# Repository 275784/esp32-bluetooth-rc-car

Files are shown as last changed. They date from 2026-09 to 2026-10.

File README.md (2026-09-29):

# ESP32 Bluetooth RC Car

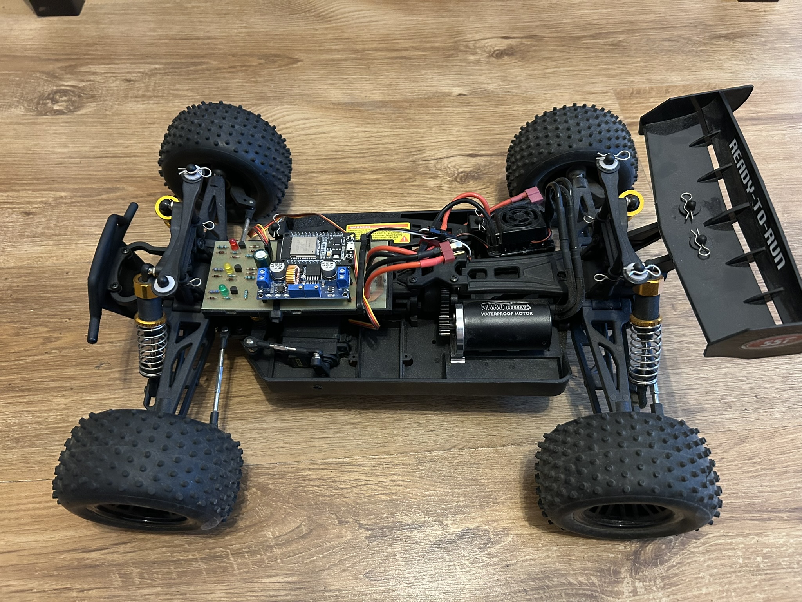
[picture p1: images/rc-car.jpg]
RC Car


Wireless RC vehicle controlled by an Xbox controller over Bluetooth.

The vehicle uses an ESP32-DevKitV1 as the main controller. The ESP32 receives commands from the Xbox controller, processes the input and generates PWM signals for the ESC and steering servo.

The system also includes a custom PCB, power distribution, battery status indication and software safety mechanisms.

## Features

- Xbox controller input over Bluetooth
- ESP32-based control system
- Brushless motor control through ESC
- Servo-based steering
- Progressive acceleration (Soft Start)
- Safe direction switching through neutral
- Run / Stop functionality
- Normal and Sport driving modes
- Battery voltage indication
- Custom PCB
- Fail-safe behavior after Bluetooth disconnection

## System Architecture

```text
Xbox Controller
      │
   Bluetooth
      │
      ▼
    ESP32
   │     │
   │     └──────► Steering Servo
   │
   └────────────► ESC ─────► Brushless Motor

LiPo Battery
      │
      ├──────────► Power Distribution
      ├──────────► Voltage Indicator
      │
      └──────────► XL4015 Step-Down
                         │
                         ├────► ESP32
                         └────► Servo
```

## How It Works

1. The Xbox controller connects to the ESP32 over Bluetooth.
2. The ESP32 reads the controller inputs and processes the commands.
3. Throttle and steering inputs are converted into PWM signals for the ESC and steering servo.
4. The battery voltage is indicated by a dedicated analog LED circuit.
5. If the Bluetooth connection is lost, the vehicle returns to a safe state.

## Hardware

- ESP32-DevKitV1
- Brushless motor
- Electronic Speed Controller (ESC)
- Steering servo
- LiPo battery
- XL4015 step-down converter
- Custom PCB
- Battery voltage indicator

## Software

- C++
- Arduino IDE
- ESP32
- Bluepad32
- ESP32Servo
- Bluetooth
- PWM

## Motor Control

The brushless motor is controlled through an Electronic Speed Controller (ESC) using a 50 Hz PWM signal.

The firmware uses:

- `1000 µs` — minimum
- `1500 µs` — neutral
- `2000 µs` — maximum

Two driving modes are available:

- **Normal**
- **Sport**

A Soft Start mechanism limits the rate at which the motor command increases.

## Steering Control

Steering is controlled using the horizontal axis of the Xbox controller.

A configurable dead zone prevents unwanted steering caused by small joystick movements.

The joystick input is mapped to the steering servo PWM range for proportional steering control.

## Safety Features

The firmware includes several mechanisms designed to prevent uncontrolled movement:

- motor output returns to neutral when the controller disconnects
- steering returns to the center position
- switching between forward and reverse requires passing through neutral
- Run / Stop functionality
- trigger dead zone
- steering dead zone
- controlled acceleration

## Hardware Design

The project includes a custom PCB integrating the ESP32, ESC interface, steering servo interface, power distribution and analog battery voltage indicator.

The PCB was designed in KiCad and the battery voltage indicator was analyzed in LTspice.

### PCB Design

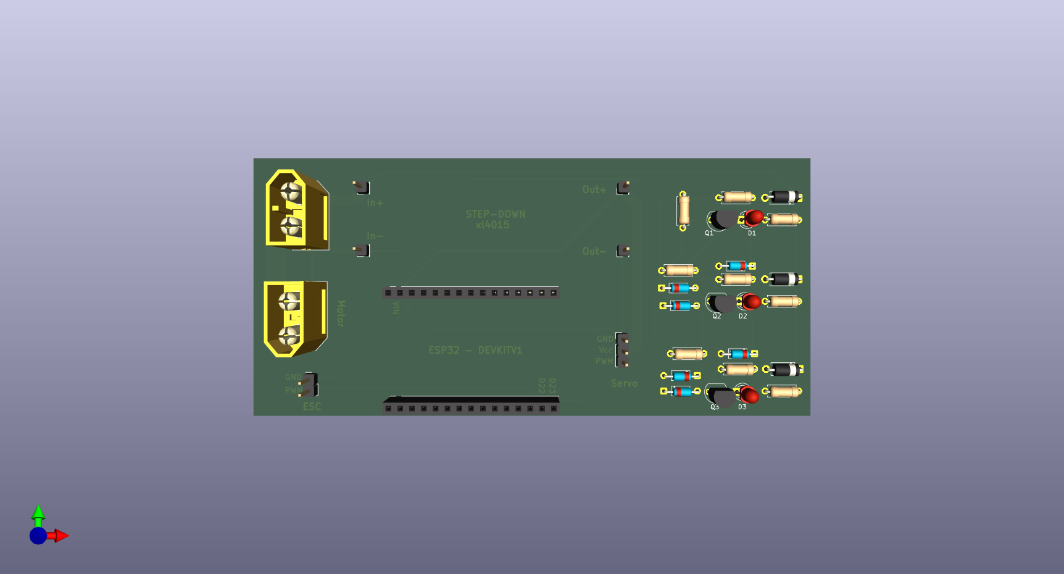
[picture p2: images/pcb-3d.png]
PCB 3D Design


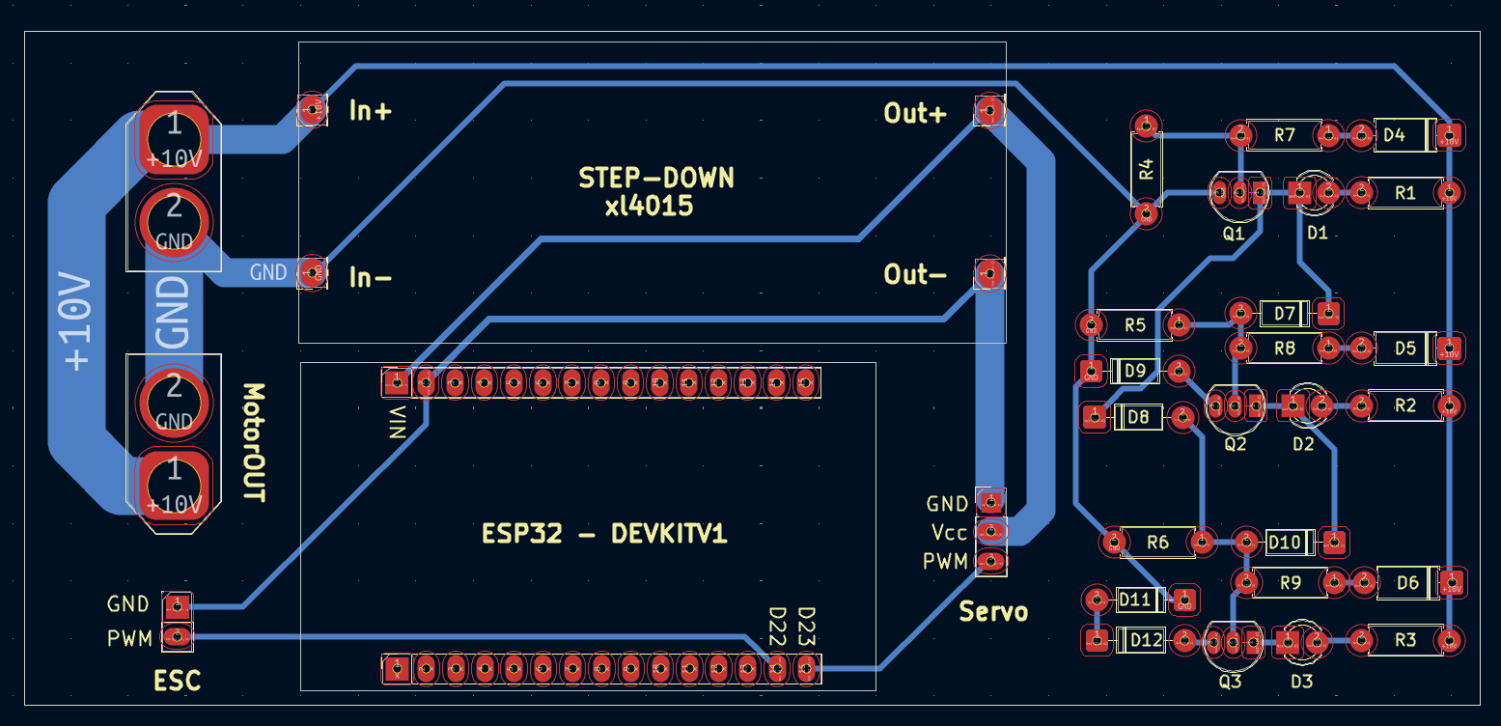
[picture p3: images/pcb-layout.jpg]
PCB Layout


### Analog Battery Voltage Indicator

The battery voltage indicator was designed and analyzed in LTspice.

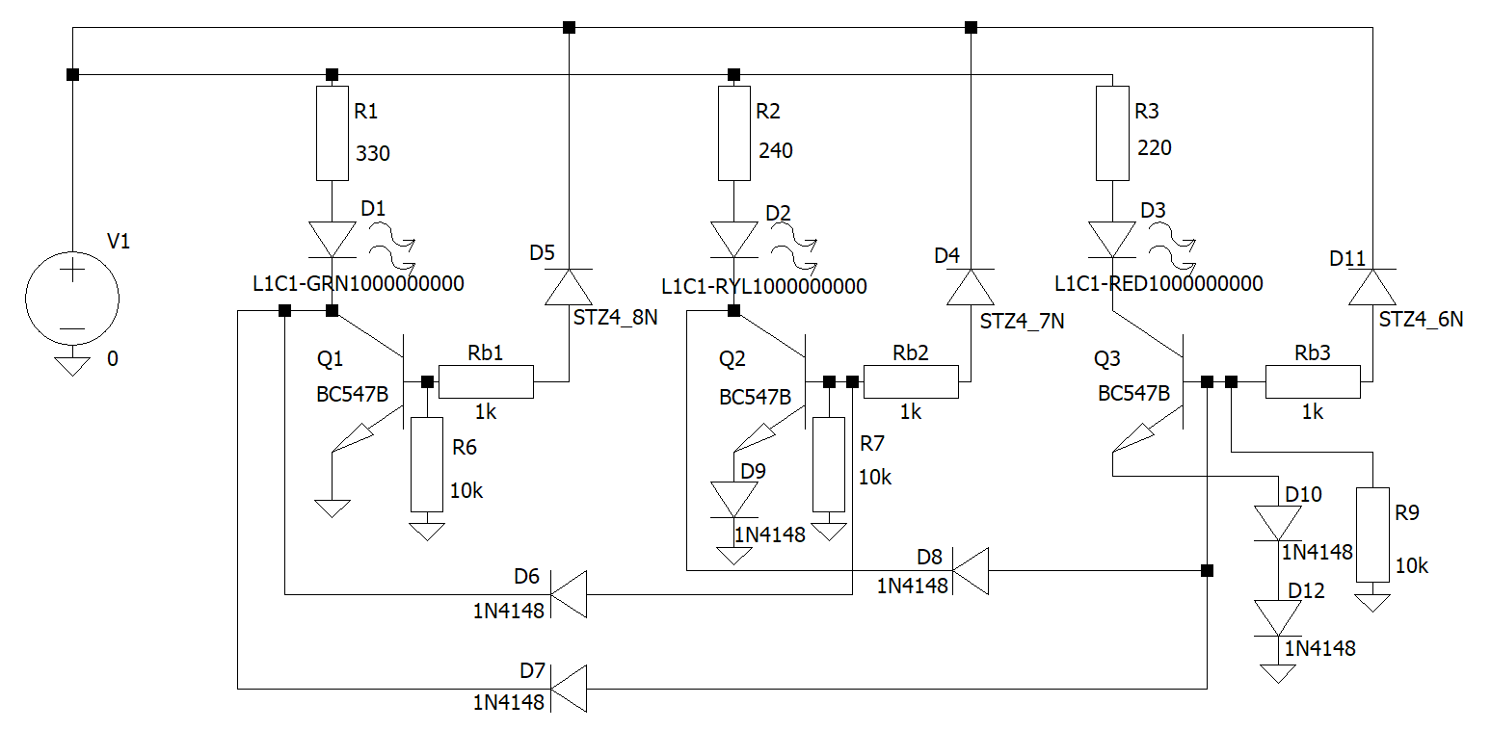
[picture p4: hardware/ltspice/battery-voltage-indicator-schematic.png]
Battery Voltage Indicator Schematic


The simulation was used to analyze the voltage thresholds and LED current characteristics of the indicator circuit.

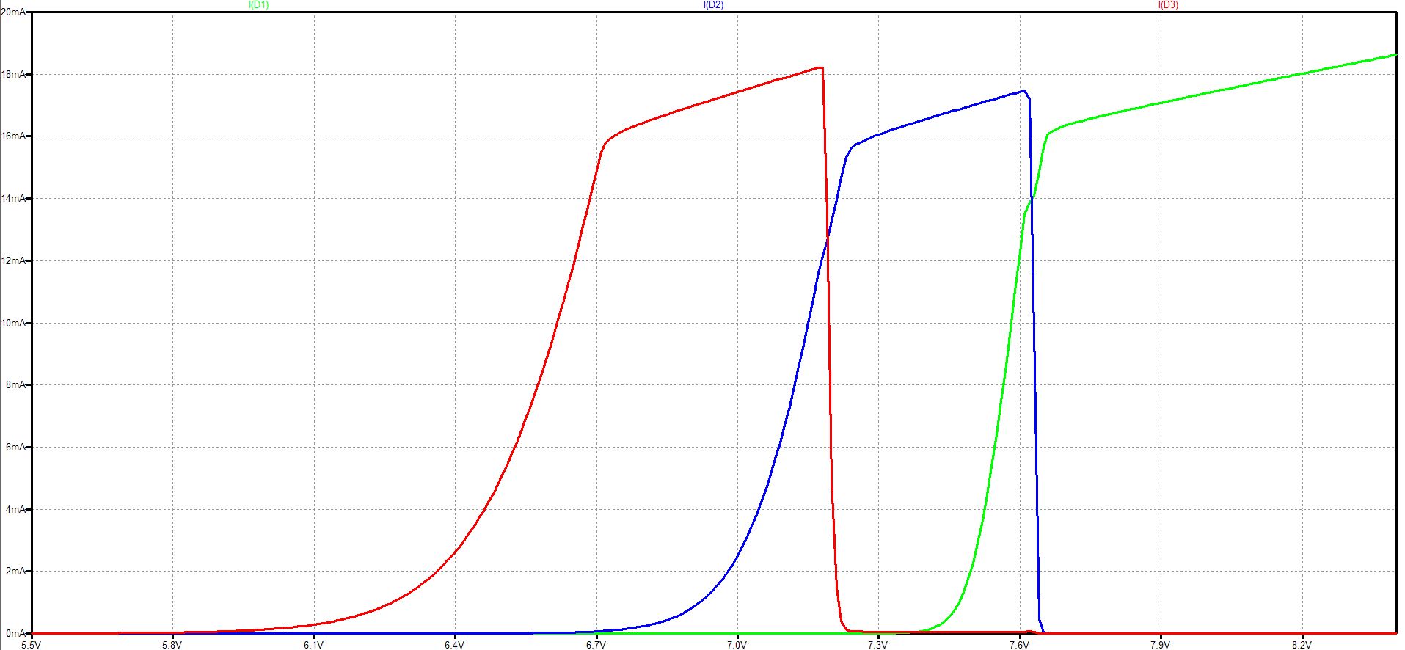
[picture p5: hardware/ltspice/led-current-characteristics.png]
LED Current Characteristics


### Design Files

- [KiCad PCB project](hardware/kicad/rc-car.kicad_pcb)
- [KiCad schematic](hardware/kicad/rc-car.kicad_sch)
- [KiCad project](hardware/kicad/rc-car.kicad_pro)
- [LTspice circuit](hardware/ltspice/battery-indicator.asc)

## My Contribution

This was a team project.

My contribution included:

- electrical schematic design
- PCB design in KiCad
- PCB assembly and soldering
- hardware integration
- system testing

## Project Status

**Completed and tested.**

## Possible Improvements

- Add obstacle detection
- Add Wi-Fi telemetry
- Add mobile monitoring
- Add live camera streaming
- Add additional sensors
- Add autonomous driving functionality

## Authors

- Konrad Misztela
- Miriam Witiw
- Maks Hula
- Mateusz Bochenek

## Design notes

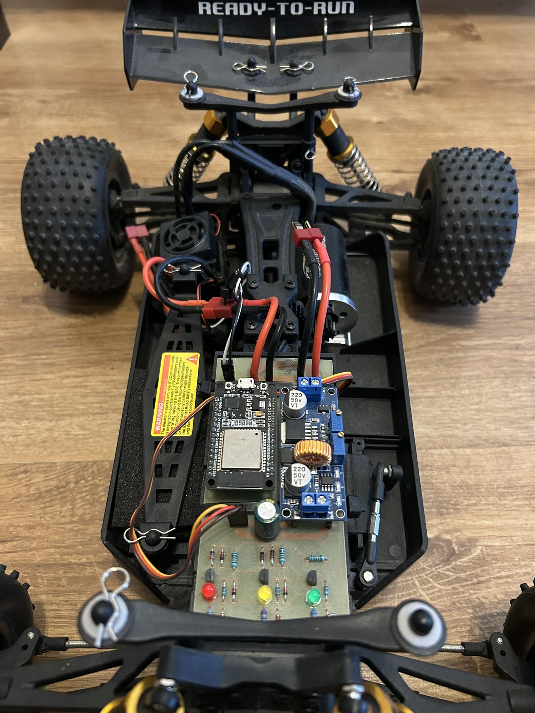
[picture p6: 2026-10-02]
images/rc-car-2.jpg

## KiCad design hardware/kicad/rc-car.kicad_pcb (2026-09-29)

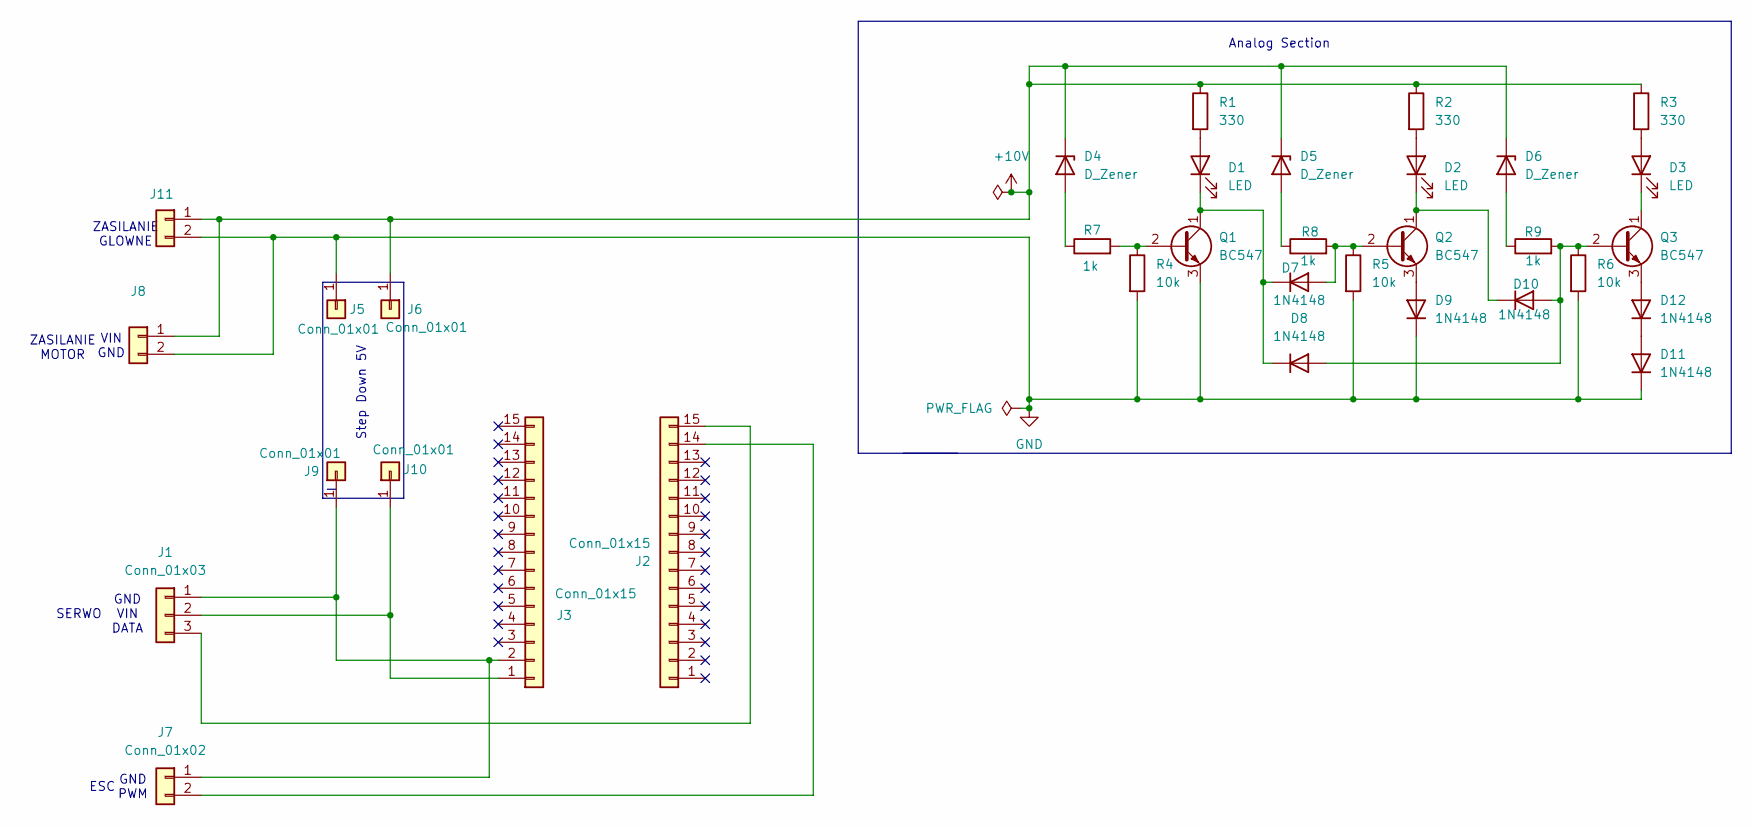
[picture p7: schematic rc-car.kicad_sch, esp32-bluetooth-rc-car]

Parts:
D1, D2, D3: LED; LED_D3.0mm
D4, D5, D6: D_Zener; D_A-405_P7.62mm_Horizontal
D7, D8, D9, D10, D11, D12: 1N4148; D_DO-35_SOD27_P7.62mm_Horizontal
J1: Conn_01x03; PinHeader_1x03_P2.54mm_Vertical
J2, J3: Conn_01x15; PinSocket_1x15_P2.54mm_Vertical
J5, J6, J9, J10: Conn_01x01; PinHeader_1x01_P2.54mm_Vertical
J7: Conn_01x02; PinHeader_1x02_P2.54mm_Vertical
J8, J11: Conn_01x02; AMASS_XT60-M_1x02_P7.20mm_Vertical
Q1, Q2, Q3: BC547; TO-92_Inline
R1, R2, R3: 330; R_Axial_DIN0207_L6.3mm_D2.5mm_P7.62mm_Horizontal
R4, R5, R6: 10k; R_Axial_DIN0207_L6.3mm_D2.5mm_P7.62mm_Horizontal
R7, R8, R9: 1k; R_Axial_DIN0207_L6.3mm_D2.5mm_P7.62mm_Horizontal

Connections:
+10V: D4.1 (K), D5.1 (K), D6.1 (K), J6.1, J8.1, J11.1, R1.1, R2.1, R3.1
GND: D9.1 (K), D11.1 (K), J5.1, J8.2, J11.2, Q1.3 (E), R4.2, R5.2, R6.2
unnamed: D1.2 (A), R1.2
unnamed: D1.1 (K), D7.1 (K), D8.1 (K), Q1.1 (C)
unnamed: D2.2 (A), R2.2
unnamed: D3.2 (A), R3.2
unnamed: D3.1 (K), Q3.1 (C)
unnamed: D4.2 (A), R7.1
unnamed: D5.2 (A), R8.1
unnamed: D6.2 (A), R9.1
unnamed: D7.2 (A), Q2.2 (B), R5.1, R8.2
unnamed: D9.2 (A), Q2.3 (E)
unnamed: D8.2 (A), D10.2 (A), Q3.2 (B), R6.1, R9.2
unnamed: D2.1 (K), D10.1 (K), Q2.1 (C)
unnamed: D11.2 (A), D12.1 (K)
unnamed: D12.2 (A), Q3.3 (E)
unnamed: J1.1, J3.2, J7.1, J9.1
unnamed: J1.2, J3.1, J10.1
unnamed: J1.3, J2.15
unnamed: J2.14, J7.2
unnamed: Q1.2 (B), R4.1, R7.2

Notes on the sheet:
VIN GND
GND PWM
Step Down 5V
SERWO
ZASILANIE MOTOR
GND VIN DATA
ZASILANIE GLOWNE
ESC
Analog Section

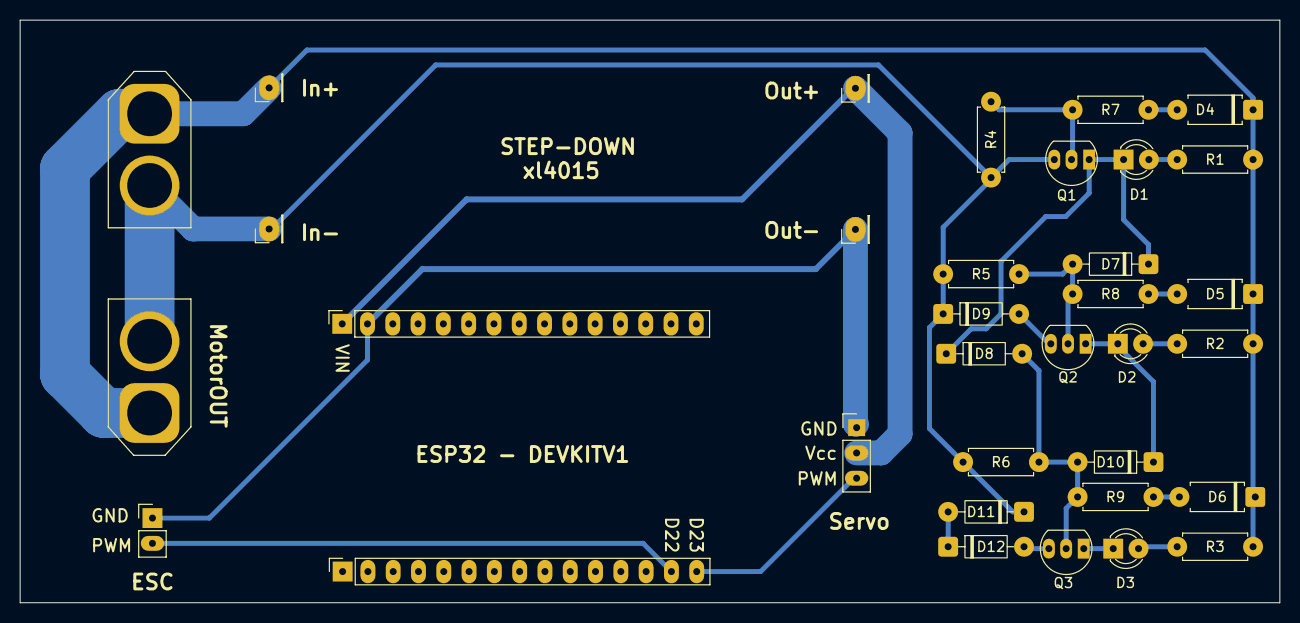
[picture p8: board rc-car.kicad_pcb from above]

Board: 2 copper layers, 126.5 x 58.5 mm, 34 parts (0 on the bottom side), 21 nets.

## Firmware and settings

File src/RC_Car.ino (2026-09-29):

#include <Bluepad32.h>
#include <ESP32Servo.h>

ControllerPtr myController = nullptr;

// SERWO
Servo esc;
Servo steeringServo;

// ESC / PWM
const int ESC_PIN = 22;          // D22 / GPIO22
const int SERVO_MIN_US = 1000;
const int SERVO_MAX_US = 2000;
const int NEUTRAL_US   = 1500;

// Martwa strefa triggerów
const int TRIGGER_DEADZONE = 40;

// SERVO SKRĘTU
const int STEERING_PIN = 23;     // D23 / GPIO23

// Ustawienia środka i zakresu
// Jeśli dalej nie jest idealnie prosto, zmieniaj CENTER np. 94, 95, 97, 98
const int STEER_CENTER_ANGLE = 96;
const int STEER_RANGE_ANGLE  = 30;   // zakres 96-30 do 96+30
const int STEER_STICK_DEADZONE = 90; // większa martwa strefa lewej gałki
const int STEER_STEP = 2;            // wolniejsze ruchy = mniejsze szarpanie
const bool STEER_INVERT = true;     // jak skręca odwrotnie, zmień na true

int currentSteerAngle = STEER_CENTER_ANGLE;
int targetSteerAngle  = STEER_CENTER_ANGLE;

// PRĘDKOŚCI
// Normalny tryb
const int FORWARD_NORMAL_MAX_US = 1840;

// Sport
const int FORWARD_SPORT_MAX_US  = 2000;

// Wsteczny
const int REVERSE_FIXED_US      = 1200;

// STANY
bool runEnabled = true;
bool sportMode = false;

// Kierunek aktywny:
//  0 = brak
//  1 = przód
// -1 = tył
int activeDirection = 0;

// Aktualny i docelowy PWM
int currentPwmUs = NEUTRAL_US;
int targetPwmUs  = NEUTRAL_US;

// Miękkie przejścia
const int ACCEL_STEP_US       = 5;
const int BRAKE_TO_NEUTRAL_US = 10;
const int REVERSE_STEP_US     = 4;
const unsigned long NEUTRAL_HOLD_MS = 180;

bool neutralHoldActive = false;
unsigned long neutralHoldStart = 0;

// Pamięć przycisków
bool prevA = false;
bool prevB = false;

// Debug
unsigned long lastPrint = 0;

// POMOCNICZE
int mapConstrainInt(int x, int inMin, int inMax, int outMin, int outMax) {
  x = constrain(x, inMin, inMax);
  return map(x, inMin, inMax, outMin, outMax);
}

void setESC(int us) {
  us = constrain(us, SERVO_MIN_US, SERVO_MAX_US);
  esc.writeMicroseconds(us);
}

void printRunState() {
  Serial.print("RUN = ");
  Serial.println(runEnabled ? "ENABLED" : "DISABLED");
}

void printSportMode() {
  Serial.print("SPORT = ");
  Serial.println(sportMode ? "ON" : "OFF");
}

void setNeutralImmediate() {
  currentPwmUs = NEUTRAL_US;
  targetPwmUs  = NEUTRAL_US;
  neutralHoldActive = false;
  setESC(NEUTRAL_US);
}

void goToSafeNeutral() {
  targetPwmUs = NEUTRAL_US;
}

void stepToward(int &value, int target, int step) {
  if (value < target) {
    value += step;
    if (value > target) value = target;
  } else if (value > target) {
    value -= step;
    if (value < target) value = target;
  }
}

bool crossesNeutral(int fromUs, int toUs) {
  return ((fromUs > NEUTRAL_US && toUs < NEUTRAL_US) ||
          (fromUs < NEUTRAL_US && toUs > NEUTRAL_US));
}

void updateMotorOutput() {
  // Najpierw łagodne przejście przez neutral
  if (crossesNeutral(currentPwmUs, targetPwmUs)) {
    stepToward(currentPwmUs, NEUTRAL_US, BRAKE_TO_NEUTRAL_US);
    setESC(currentPwmUs);

    if (currentPwmUs == NEUTRAL_US) {
      if (!neutralHoldActive) {
        neutralHoldActive = true;
        neutralHoldStart = millis();
      }

      if (millis() - neutralHoldStart < NEUTRAL_HOLD_MS) {
        return;
      } else {
        neutralHoldActive = false;
      }
    } else {
      neutralHoldActive = false;
      return;
    }
  } else {
    neutralHoldActive = false;
  }

  int step = ACCEL_STEP_US;

  if (targetPwmUs == NEUTRAL_US) {
    step = BRAKE_TO_NEUTRAL_US;
  }

  if (currentPwmUs < NEUTRAL_US || targetPwmUs < NEUTRAL_US) {
    step = REVERSE_STEP_US;
  }

  stepToward(currentPwmUs, targetPwmUs, step);
  setESC(currentPwmUs);
}

int getForwardTarget(int rt) {
  int maxUs = sportMode ? FORWARD_SPORT_MAX_US : FORWARD_NORMAL_MAX_US;
  return mapConstrainInt(rt, TRIGGER_DEADZONE, 1023, NEUTRAL_US, maxUs);
}

int getReverseTarget(int lt) {
  return mapConstrainInt(lt, TRIGGER_DEADZONE, 1023, NEUTRAL_US, REVERSE_FIXED_US);
}

// STEROWANIE SERWEM
void setSteeringImmediate(int angle) {
  int minAngle = STEER_CENTER_ANGLE - STEER_RANGE_ANGLE;
  int maxAngle = STEER_CENTER_ANGLE + STEER_RANGE_ANGLE;

  angle = constrain(angle, minAngle, maxAngle);
  currentSteerAngle = angle;
  targetSteerAngle = angle;
  steeringServo.write(angle);
}

int getSteeringTargetFromStick(int axisX) {
  // Bluepad32: lewa gałka poziomo zwykle około -512 ... 512
  if (abs(axisX) < STEER_STICK_DEADZONE) {
    return STEER_CENTER_ANGLE;
  }

  int x = constrain(axisX, -512, 512);

  if (STEER_INVERT) {
    x = -x;
  }

  int minAngle = STEER_CENTER_ANGLE - STEER_RANGE_ANGLE;
  int maxAngle = STEER_CENTER_ANGLE + STEER_RANGE_ANGLE;

  return map(x, -512, 512, minAngle, maxAngle);
}

void updateSteeringOutput() {
  stepToward(currentSteerAngle, targetSteerAngle, STEER_STEP);
  steeringServo.write(currentSteerAngle);
}

void processSteering(ControllerPtr gp) {
  int axisX = gp->axisX();   // lewa gałka poziomo
  targetSteerAngle = getSteeringTargetFromStick(axisX);
}

// CALLBACKI BLUEPAD32
void onConnectedController(ControllerPtr ctl) {
  if (myController == nullptr) {
    myController = ctl;
    Serial.println("Pad polaczony");

    ControllerProperties p = ctl->getProperties();
    char buf[120];
    sprintf(buf, "VID/PID: %04x:%04x, flags: 0x%02x",
            p.vendor_id, p.product_id, p.flags);
    Serial.println(buf);

    printRunState();
    printSportMode();
  } else {
    Serial.println("Juz mam podlaczony jeden pad, ignoruje kolejny");
  }
}

void onDisconnectedController(ControllerPtr ctl) {
  if (myController == ctl) {
    myController = nullptr;
    runEnabled = false;
    activeDirection = 0;
    setNeutralImmediate();
    setSteeringImmediate(STEER_CENTER_ANGLE);
    Serial.println("Pad rozlaczony");
  }
}

// PRZYCISKI
void processButtons(ControllerPtr gp) {
  bool a = gp->a();
  bool b = gp->b();

  // A = SPORT ON / OFF
  if (a && !prevA) {
    sportMode = !sportMode;
    activeDirection = 0;
    goToSafeNeutral();
    printSportMode();
  }

  // B = RUN / STOP
  if (b && !prevB) {
    runEnabled = !runEnabled;
    activeDirection = 0;
    goToSafeNeutral();
    printRunState();
  }

  prevA = a;
  prevB = b;
}

// JAZDA
void processDrive(ControllerPtr gp) {
  int rt = gp->throttle();   // 0..1023
  int lt = gp->brake();      // 0..1023

  bool rtPressed = (rt > TRIGGER_DEADZONE);
  bool ltPressed = (lt > TRIGGER_DEADZONE);

  // STOP = wszystko ignorowane
  if (!runEnabled) {
    activeDirection = 0;
    targetPwmUs = NEUTRAL_US;
    return;
  }

  // Oba triggery naraz = neutral
  if (rtPressed && ltPressed) {
    activeDirection = 0;
    targetPwmUs = NEUTRAL_US;
    return;
  }

  // Jeśli aktywny był przód
  if (activeDirection == 1) {
    // Próba przejścia na tył bez puszczenia gazu -> najpierw neutral
    if (ltPressed && !rtPressed) {
      activeDirection = 0;
      targetPwmUs = NEUTRAL_US;
      return;
    }

    // Puściłeś RT
    if (!rtPressed) {
      activeDirection = 0;
      targetPwmUs = NEUTRAL_US;
      return;
    }
  }

  // Jeśli aktywny był tył
  else if (activeDirection == -1) {
    // Próba przejścia na przód bez puszczenia tyłu -> najpierw neutral
    if (rtPressed && !ltPressed) {
      activeDirection = 0;
      targetPwmUs = NEUTRAL_US;
      return;
    }

    // Puściłeś LT
    if (!ltPressed) {
      activeDirection = 0;
      targetPwmUs = NEUTRAL_US;
      return;
    }
  }

  // Brak aktywnego kierunku
  else {
    if (rtPressed && !ltPressed) {
      activeDirection = 1;
    } else if (ltPressed && !rtPressed) {
      activeDirection = -1;
    } else {
      targetPwmUs = NEUTRAL_US;
      return;
    }
  }

  // Wyznaczanie celu PWM
  if (activeDirection == 1 && rtPressed) {
    targetPwmUs = getForwardTarget(rt);
  } else if (activeDirection == -1 && ltPressed) {
    targetPwmUs = getReverseTarget(lt);
  } else {
    targetPwmUs = NEUTRAL_US;
  }
}

void processGamepad(ControllerPtr gp) {
  processButtons(gp);
  processDrive(gp);
  processSteering(gp);

  if (millis() - lastPrint > 250) {
    lastPrint = millis();

    Serial.print("RUN=");
    Serial.print(runEnabled ? "ON" : "OFF");
    Serial.print(" SPORT=");
    Serial.print(sportMode ? "ON" : "OFF");
    Serial.print(" DIR=");
    Serial.print(activeDirection);
    Serial.print(" CUR=");
    Serial.print(currentPwmUs);
    Serial.print(" TAR=");
    Serial.print(targetPwmUs);
    Serial.print(" RT=");
    Serial.print(gp->throttle());
    Serial.print(" LT=");
    Serial.print(gp->brake());
    Serial.print(" STICK_X=");
    Serial.print(gp->axisX());
    Serial.print(" STEER=");
    Serial.println(targetSteerAngle);
  }
}

// SETUP
void setup() {
  Serial.begin(115200);
  delay(1000);

  esc.setPeriodHertz(50);
  esc.attach(ESC_PIN, SERVO_MIN_US, SERVO_MAX_US);
  setNeutralImmediate();

  steeringServo.setPeriodHertz(50);
  steeringServo.attach(STEERING_PIN, 500, 2400);
  setSteeringImmediate(STEER_CENTER_ANGLE);

  Serial.println("Start ESP32 + Xbox + ESC + STEERING");
  Serial.println("D22/GPIO22 -> SIGNAL ESC");
  Serial.println("D23/GPIO23 -> SERVO SKRETU");
  Serial.println("GND ESP32 musi byc wspolne z GND ESC i GND serwa");
  Serial.println("RT = przod");
  Serial.println("LT = tyl / hamowanie");
  Serial.println("Lewa galka poziomo = skret kol");
  Serial.println("A = SPORT ON/OFF");
  Serial.println("B = RUN / STOP");
  Serial.println("Bez biegow");
  Serial.println("Bez AUTO/MANUAL");

  BP32.setup(&onConnectedController, &onDisconnectedController);

  // Odkomentuj tylko raz, jesli chcesz skasowac stare sparowane urzadzenia:
  // BP32.forgetBluetoothKeys();

  const uint8_t* addr = BP32.localBdAddress();
  Serial.print("BT MAC ESP32: ");
  for (int i = 0; i < 6; i++) {
    Serial.print(addr[i], HEX);
    if (i < 5) Serial.print(":");
  }
  Serial.println();

  printRunState();
  printSportMode();
}


// LOOP
void loop() {
  BP32.update();

  if (myController && myController->isConnected() && myController->isGamepad()) {
    processGamepad(myController);
  } else {
    targetPwmUs = NEUTRAL_US;
    targetSteerAngle = STEER_CENTER_ANGLE;
  }

  updateMotorOutput();
  updateSteeringOutput();
  delay(10);
}
